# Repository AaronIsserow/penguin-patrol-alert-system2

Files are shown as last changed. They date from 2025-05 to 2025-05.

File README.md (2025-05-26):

# 🐧 Penguin Patrol Alert System

## Table of Contents

- [Project Overview](#project-overview)  
- [Key Features](#key-features)  
- [Architecture & Tech Stack](#architecture--tech-stack)  
- [Mechanical Design & 3D Printing](#mechanical-design--3d-printing)
- [Motion Detection](#motion-detection)
- [Installation & Setup](#installation--setup)

---

## Project Overview

**Penguin Patrol Alert System** is a full-stack web application developed for **EEE4113F** at the University of Cape Town. It integrates real-time predator detection (via computer vision and a Raspberry Pi NoIR camera) with a two-axis pan–tilt gimbal and non-lethal deterrent actuation. Alerts are stored and displayed through a user-friendly dashboard, ensuring rapid intervention to protect the De Hoop penguin colony.

---

## Key Features

- 🎥 **Live Video Streaming** with motion-detection overlays  
- 🔴 **Real-Time Alerts** stored in Supabase and pushed via WebSockets  
- 🛰️ **Pan–Tilt Gimbal Control** for ±90° tracking accuracy  
- 💧 **Non-Lethal Deterrent** (configurable water-jet or laser)  
- 📊 **Dashboard & Analytics** with CSV export  
- 🔧 **Modular Mechanical Design** with 3D-printed submodules

### Basic Example Operation

systemuse (2)

---

## Architecture & Tech Stack

| Layer | Technology |
|---|---|
| **Frontend** | React, Tailwind CSS |
| **Backend / API** | Node.js, Supabase (PostgreSQL) |
| **Realtime Comm.**  | Supabase Realtime |
| **Vision & Control**| Python, OpenCV, pigpio, Raspberry Pi OS |
| **3D Modeling** | Fusion 360 (CAD) |
| **3D Printing** | Cura / PrusaSlicer |

---

## Mechanical Design & 3D Printing

Detailed mechanical design ensures precise servo alignment, environmental sealing, and easy assembly. All parts were 3D-printed and validated with FEA before prototyping.

Linking v2

## Assembly

Linking v1

### Printed Components

| Part | Description | Qty |
|---|---|:---:|
| **Pan Module** | Base plate with servo pocket & mounts  |  1  |
| **Tilt Module** | Horizontal servo carrier & gussets |  1  |
| **Enclosure Base**| IP66-ready housing (bottom half) |  1  |
| **Enclosure Lid** | Snap-fit top cover with gasket groove  |  1  |
| **Fence Clip** | Modular mount for fence attachment |  1  |

<p align="center">
  3D Printed Parts
</p>

### Materials & Settings

- **Filament:**  
  - **UV-stable ASA** for outdoor parts  
  - **PLA+** for enclosure prototypes  
- **Printer:** Creality CR-10 / Prusa i3 MK3S+  
- **Layer Height:** 0.2 mm, **Infill:** 20 %, **Walls:** 3 perimeters  
- **Nozzle Temp:** 240 °C (ASA) / 210 °C (PLA+),  
  **Bed Temp:** 100 °C (ASA) / 60 °C (PLA+)

### CAD & STL Files

All source and exported STLs live in the `MechanicalDesign/` folder:
design/
├─ pan_module.f3d pan_module.stl
├─ tilt_module.f3d tilt_module.stl
├─ enclosure_base.f3d enclosure_base.stl
└─ enclosure_lid.f3d enclosure_lid.stl

## Motion Detection

The Penguin Patrol Alert System employs an advanced real-time motion detection algorithm running on a Raspberry Pi with a NoIR camera module. This enables reliable predator detection even under challenging lighting conditions.

- **Algorithm Overview:**  
  - The system captures continuous frames from the NoIR camera and applies frame differencing to highlight regions of change between consecutive images.  
  - To reduce noise and false positives caused by environmental factors (e.g., shadows, lighting changes), a Gaussian blur filter is applied before differencing.  
  - The resulting difference image is thresholded to create a binary mask representing motion regions.  
  - Contours are extracted from this binary mask and filtered based on area and shape criteria to isolate valid moving objects.  
  - Temporal filtering tracks object persistence over multiple frames to avoid transient false detections.  
- **Hardware:** Raspberry Pi Camera Module V2 NoIR is used for its enhanced infrared sensitivity, combined with optional IR LED illumination for night-time detection.  
- **Control Integration:** Upon detection, the Python-based control script commands the pan–tilt gimbal servos via GPIO using pigpio, allowing smooth tracking of detected objects within ±90° range.  
- **Alerting:** Simultaneously, detection events are logged and pushed in real-time to the Supabase backend, enabling live notifications and historical analytics through the web dashboard.  
- **Configuration:** Parameters such as blur kernel size, threshold values, minimum contour area, and tracking persistence are adjustable in the `motionsense.py` file to optimize system performance under varying environmental conditions.

This comprehensive detection pipeline balances sensitivity with robustness, ensuring reliable predator tracking while minimizing false alarms to protect the penguin colony effectively.

## Installation & Setup

1. **Clone the repository**  
   ```bash
   git clone https://github.com/AaronIsserow/penguin-patrol-alert-system2.git

2. **Install Dependencies**
  npm install                  # Frontend & API
3. Create a .env file in the root directory with your API keys:
  - OpenAI API key for chatbot
  - Supabase credentials
4. Start the development server:
    npm run dev

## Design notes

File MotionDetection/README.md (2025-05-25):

# 🛰️ Motion Detection Subsystem — Turret Project

This folder contains the motion detection and control logic used in the automated turret project. It combines lightweight computer vision, real-time hardware actuation, and cloud-based logging to detect and track movement within a camera's field of view.

---

## 📚 Background

### 📷 Motion Detection Overview (Using OpenCV)

The system uses **frame differencing**, a classic motion detection technique, where each incoming frame is compared against a stabilized background. The open source image processing library OpenCV handles the following steps:

- **Frame capture** from the Pi Camera.
- **Grayscale conversion** and **Gaussian blur** to reduce noise.
- **Absolute difference** between the current frame and a reference background.
- **Thresholding** and **morphological operations** to isolate moving regions.
- **Contour detection** to identify the largest significant object.

If the detected contour exceeds a pixel area threshold, it's considered significant motion. The center of the bounding box is calculated and used to point the turret in that direction.

> This method is fast and lightweight, ideal for low-power hardware, but is sensitive to lighting changes and assumes a mostly static background.

---

### 🧰 Hardware Architecture

| Component | Role |
|---|---|
| Raspberry Pi 3B+ | Main processing unit, runs detection and Flask server. |
| Pi Camera V2 NoIR | Captures frames for processing, with infrared sensitivity for low-light. |
| Servo Motors (x2) | Controlled via PWM to adjust turret pan and tilt. |
| IR LED Module (opt.)  | Recommended for improving night detection performance. |

---

## 📁 Folder Contents

| File | Description |
|---|---|
| `motionsense5.py` | Captures video, detects motion, controls servos, logs to Supabase, and streams annotated video. |
| `flask_controller.py` | Flask server exposing `/start`, `/stop`, and `/status` endpoints, also updates system status in Supabase. |

---

## ⚙️ motionsense5.py — Motion Detection Engine

- Initializes camera and background model.
- Detects motion using image differencing + contour filtering.
- Translates motion coordinates to servo angles using a calibrated FOV.
- Controls pan and tilt servos via `pigpio`.
- Logs each detection to a Supabase table with timestamp and location.
- Streams live video with bounding box overlays via a `/video_feed` endpoint.

---

## 🌐 flask_controller.py — Remote API Interface

A lightweight Flask server for remote subsystem control:

**Endpoints:**
- `POST /start` — Launches `motionsense5.py`.
- `POST /stop` — Terminates detection and resets servos.
- `GET /status` — Returns whether detection is active.

It also sets the `status` field in Supabase's `perimeters` table to reflect system state (boot, shutdown, and manual control).

---

## 🔐 Environment Variables

Create a `.env` file:

```dotenv
SUPABASE_URL=https://your-project.supabase.co
SUPABASE_KEY=your-supabase-service-role-key

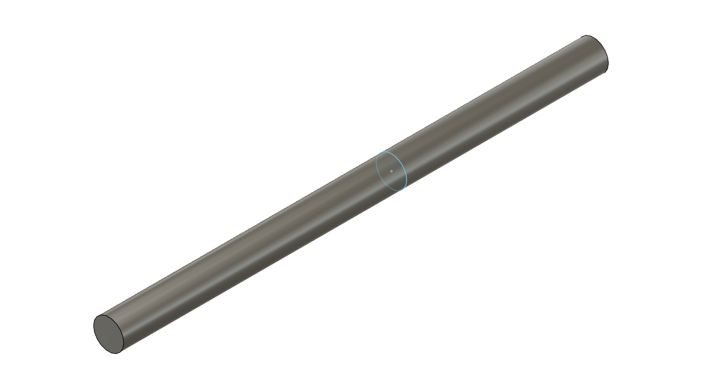
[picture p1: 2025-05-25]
Mechanical Design/HingePin v1.png

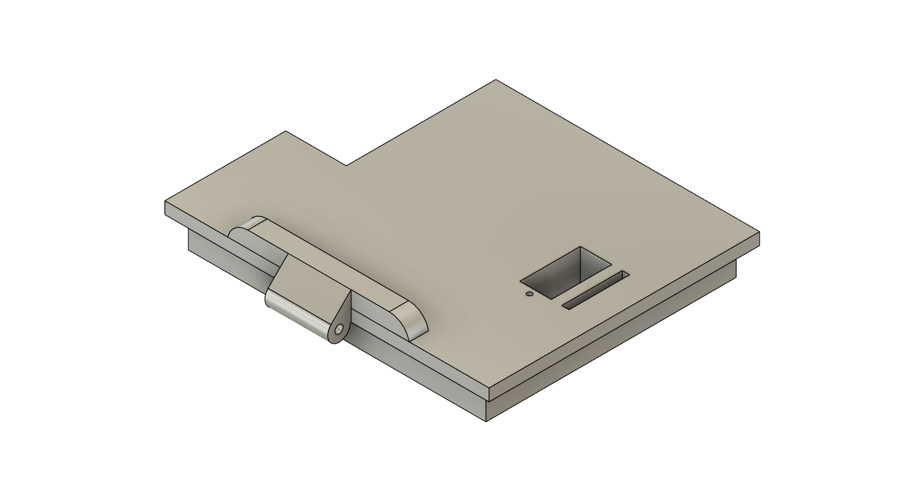
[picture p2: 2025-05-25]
Mechanical Design/CaseLid v10 v7.png

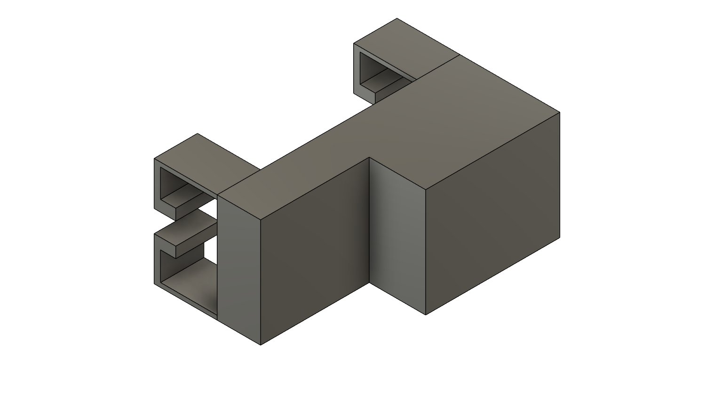
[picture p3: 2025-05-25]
Mechanical Design/FenceConnector v2.png

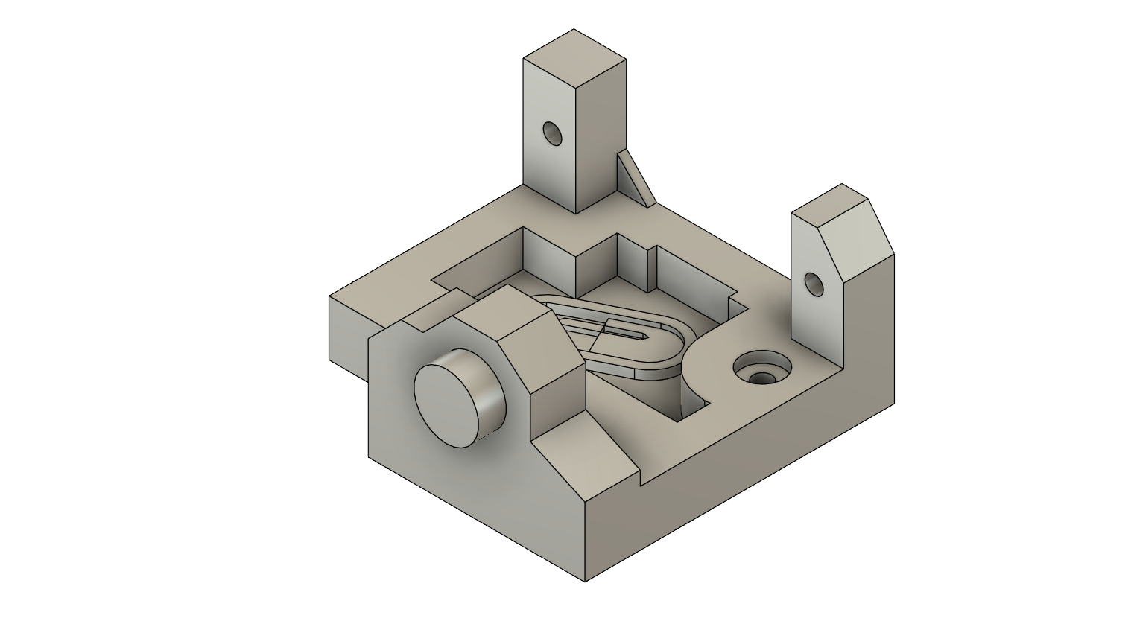
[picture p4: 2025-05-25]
Mechanical Design/Body v11.png

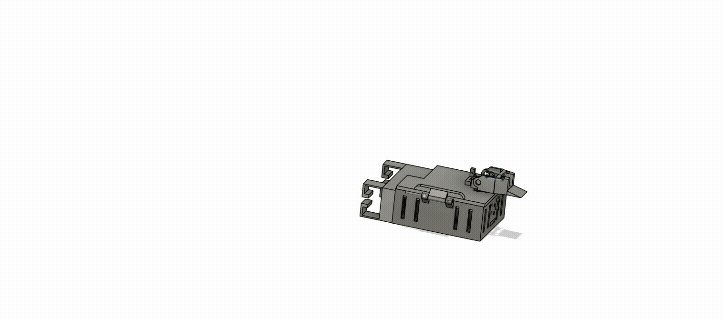
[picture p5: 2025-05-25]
Videos/Linking v1.gif

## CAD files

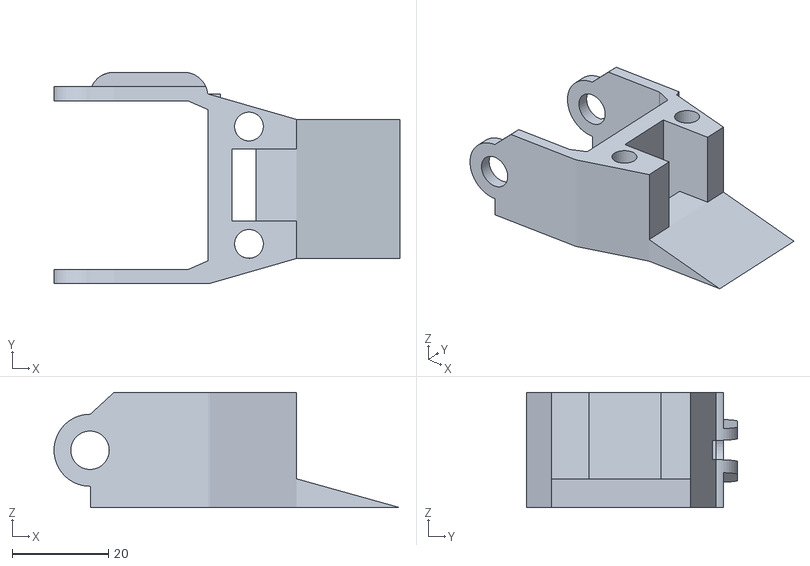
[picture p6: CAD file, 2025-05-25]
Mechanical Design/Tilt.stl
72.0 x 44.0 x 24.0

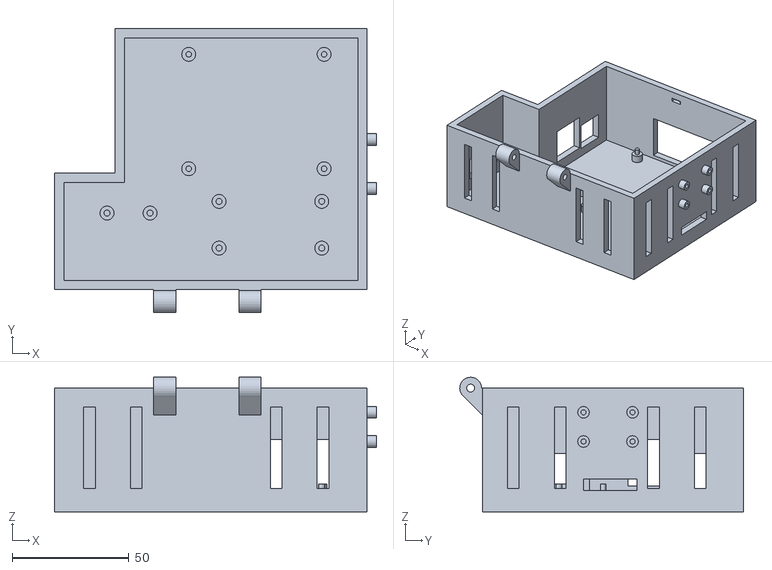
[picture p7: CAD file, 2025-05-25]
Mechanical Design/CaseV30.stl
138.0 x 121.5 x 57.7

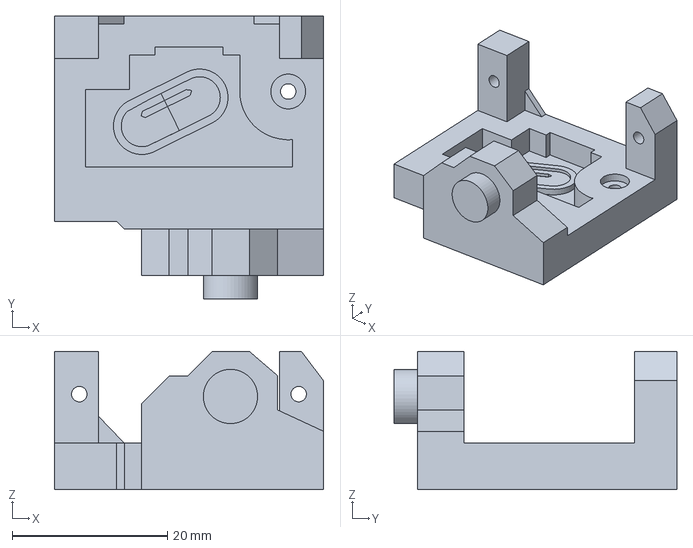
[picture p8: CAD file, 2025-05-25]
Mechanical Design/Final Body.3mf
34.7 x 36.5 x 17.8 mm

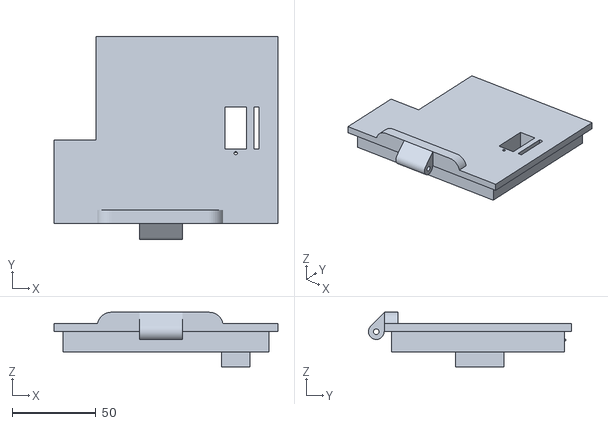
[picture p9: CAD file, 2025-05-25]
Mechanical Design/CaseLidV10V6.stl
134.0 x 121.5 x 32.7

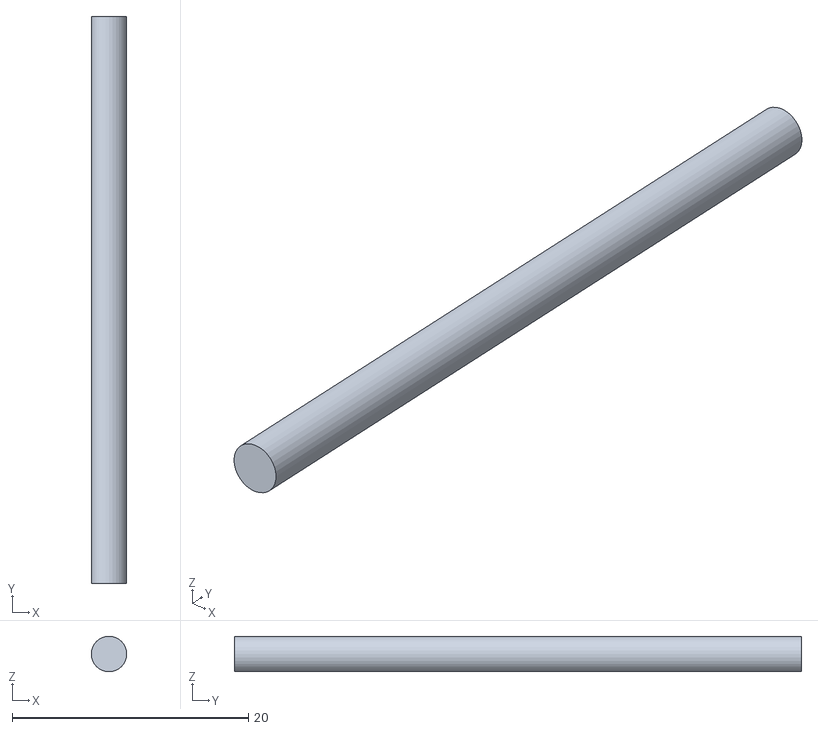
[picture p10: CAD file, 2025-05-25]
Mechanical Design/HingePin.stl
3.00 x 48.0 x 3.00

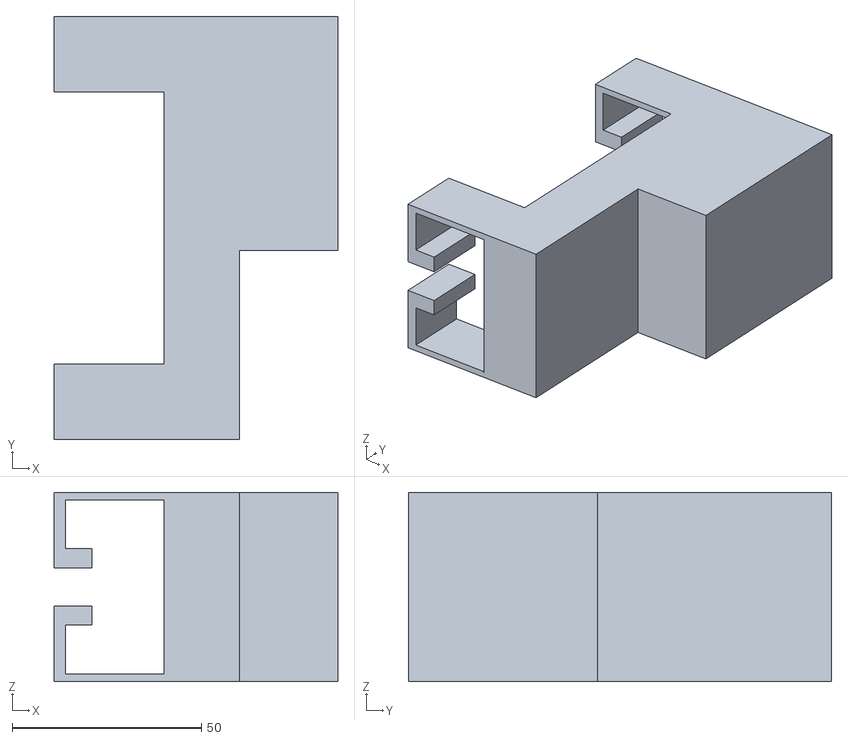
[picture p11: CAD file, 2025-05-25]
Mechanical Design/FenceAttachment.stl
75.0 x 111.8 x 50.0

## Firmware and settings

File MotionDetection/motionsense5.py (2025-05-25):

# --------------------------------------------------------------
# Imports
import cv2
import numpy as np
import time
import RPi.GPIO as GPIO
import pigpio
import math
from datetime import datetime, timedelta
from threading import Thread, Lock
from flask import Flask, Response
from flask_cors import CORS
from picamera2 import Picamera2
from supabase import create_client, Client
from dotenv import load_dotenv
import os

# --------------------------------------------------------------
# Load environment variables from .env file
load_dotenv()

# --------------------------------------------------------------
# Flask App Setup
app = Flask(__name__)
CORS(app)  # Enable Cross-Origin Resource Sharing for frontend integration

# --------------------------------------------------------------
# Supabase Configuration
SUPABASE_URL = os.getenv("SUPABASE_URL")
SUPABASE_KEY = os.getenv("SUPABASE_KEY")
supabase: Client = create_client(SUPABASE_URL, SUPABASE_KEY)

# --------------------------------------------------------------
# Camera Setup
picam2 = Picamera2()
picam2.preview_configuration.main.size = (960, 540)  # Set resolution
picam2.preview_configuration.main.format = "RGB888"
picam2.preview_configuration.align()
picam2.configure("preview")
picam2.start()  # Start video stream

# --------------------------------------------------------------
# Servo Setup
PAN_GPIO = 12
TILT_GPIO = 13
PAN_MIN_ANGLE = -90
PAN_MAX_ANGLE = 90
PAN_OFFSET = 20
TILT_MIN_ANGLE = -30
TILT_MAX_ANGLE = 60
TILT_OFFSET = 20

pi = pigpio.pi()
if not pi.connected:
    raise RuntimeError("Cannot connect to pigpio daemon")

# Convert image center coordinates to servo angles
def pixel_to_angle(cx, cy, frame_w, frame_h):
    dx = cx - frame_w/2
    dy = cy - frame_h/2
    frac_x = dx / (frame_w / 2)
    frac_y = dy / (frame_h / 2)
    pan_angle = -frac_x * (FOV_X_DEG) + PAN_OFFSET
    tilt_angle = frac_y * (FOV_Y_DEG) + TILT_OFFSET
    pan_angle = max(PAN_MIN_ANGLE, min(PAN_MAX_ANGLE, pan_angle))
    tilt_angle = max(TILT_MIN_ANGLE, min(TILT_MAX_ANGLE, tilt_angle))
    return pan_angle, tilt_angle

# Convert angle to PWM pulse width for servo
def angle_to_pw(angle):
    angle = max(-90, min(90, angle))
    pulse = 1500 + (angle / 90.0) * 500
    return max(1000, min(2000, pulse))

# Move servos to target coordinates
def move_servos(cx, cy, frame_w, frame_h):
    pan_angle, tilt_angle = pixel_to_angle(cx, cy, frame_w, frame_h)
    pi.set_servo_pulsewidth(PAN_GPIO, angle_to_pw(pan_angle))
    pi.set_servo_pulsewidth(TILT_GPIO, angle_to_pw(tilt_angle))

# Reset servos and LED when shutting down
def shutdown_servos():
    pi.set_servo_pulsewidth(PAN_GPIO, 0)
    pi.set_servo_pulsewidth(TILT_GPIO, 0)
    pi.write(LED_PIN, 0)
    pi.stop()

# --------------------------------------------------------------
# LED GPIO Setup
LED_PIN = 26
pi.set_mode(LED_PIN, pigpio.OUTPUT)

# --------------------------------------------------------------
# Globals for Motion Detection
first_frame = None
temp_frame = None
stabilized_count = 0
required_stable_frames = 20
MOTION_THRESHOLD = 5000
lock = Lock()
FOV_X_DEG = 62.2 - 15  # Adjusted field of view
FOV_Y_DEG = 48.8
UPDATE_INTERVAL = 0.05
last_update_time = 0
latest_frame = None
frame_lock = Lock()

# --------------------------------------------------------------
# Supabase Logging
def log_motion_event():
    timestamp = datetime.now().isoformat()
    try:
        data = {
            "location": "Perimeter A",
            "time": timestamp,
            "action_taken": "Laser deployed",
            "acknowledged": False
        }
        supabase.table("detections").insert(data).execute()
        print(f"Motion logged to Supabase at {timestamp}")
    except Exception as e:
        print(f"Supabase logging failed: {e}")

# --------------------------------------------------------------
# Identify best contour above a pixel area threshold
def get_best_contour(imgmask, threshold):
    contours, _ = cv2.findContours(imgmask, cv2.RETR_EXTERNAL, cv2.CHAIN_APPROX_SIMPLE)
    best_area = threshold
    best_cnt = None
    for cnt in contours:
        area = cv2.contourArea(cnt)
        if area > best_area:
            best_area = area
            best_cnt = cnt
    return best_cnt

# --------------------------------------------------------------
# Reset background model for stabilization
def reset_stabilization():
    global first_frame, temp_frame, stabilized_count
    first_frame = None
    temp_frame = None
    stabilized_count = 0
    print("Recalibrating background frame...")

# --------------------------------------------------------------
# Main Motion Detection Loop (runs in thread)
def motion_detection_loop():
    global first_frame, temp_frame, stabilized_count, last_update_time, latest_frame
    motion_active = False
    last_alert_time = None
    print("Waiting for camera to stabilize...")

    recalibration_interval = timedelta(minutes=5)
    last_recalibration_time = datetime.utcnow()

    while True:
        now = datetime.utcnow()
        if now - last_recalibration_time >= recalibration_interval:
            reset_stabilization()
            last_recalibration_time = now

        # Capture frame
        frame = picam2.capture_array()
        gray = cv2.cvtColor(frame, cv2.COLOR_RGB2GRAY)
        gray = cv2.GaussianBlur(gray, (21, 21), 0)

        with lock:
            if first_frame is None:
                if temp_frame is None:
                    temp_frame = gray
                    continue
                delta = cv2.absdiff(temp_frame, gray)
                temp_frame = gray
                diff = cv2.threshold(delta, 10, 255, cv2.THRESH_BINARY)[1]
                diff = cv2.dilate(diff, None, iterations=2)
                motion_pixels = cv2.countNonZero(diff)

                if motion_pixels < 300:
                    stabilized_count += 1
                    if stabilized_count >= required_stable_frames:
                        first_frame = gray
                        print("Stabilized. Motion detection activated.")
                        continue
                else:
                    stabilized_count = 0
                continue

            # Compare current frame to background
            delta = cv2.absdiff(first_frame, gray)
            thresh = cv2.threshold(delta, 30, 255, cv2.THRESH_BINARY)[1]
            thresh = cv2.dilate(thresh, None, iterations=2)

            best_contour = get_best_contour(thresh.copy(), threshold=MOTION_THRESHOLD)

            if best_contour is not None:
                (x, y, w, h) = cv2.boundingRect(best_contour)
                frame_h, frame_w = frame.shape[:2]
                cx, cy = x + w // 2, y + h // 2

                move_servos(cx, cy, frame_w, frame_h)
                pi.write(LED_PIN, 1)  # Turn on LED to indicate motion

                # Draw detection box
                cv2.rectangle(frame, (x, y), (x + w, y + h), (0, 255, 0), 2)
                cv2.putText(frame, "Motion Detected", (10, 20),
                            cv2.FONT_HERSHEY_SIMPLEX, 0.6, (0, 0, 255), 2)

                now = datetime.utcnow()
                if not motion_active:
                    motion_active = True
                    last_alert_time = now
                    log_motion_event()
                    print("Motion started, alert sent.")
                elif (now - last_alert_time).total_seconds() >= 60:
                    log_motion_event()
                    last_alert_time = now
                    print("Motion ongoing, secondary alert sent")
            else:
                pi.write(LED_PIN, 0)  # Turn off LED
                if motion_active:
                    print("Motion stopped")
                    motion_active = False
                    last_alert_time = None

        # Encode frame for live video streaming
        ret, jpeg = cv2.imencode('.jpg', frame)
        if ret:
            with frame_lock:
                latest_frame = jpeg.tobytes()

# --------------------------------------------------------------
# Flask Route: /video_feed returns MJPEG stream
@app.route('/video_feed')
def video_feed():
    def frame_generator():
        while True:
            with frame_lock:
                frame = latest_frame
            if frame:
                yield (b'--frame\r\n'
                       b'Content-Type: image/jpeg\r\n\r\n' + frame + b'\r\n')
            time.sleep(0.05)
    return Response(frame_generator(),
                    mimetype='multipart/x-mixed-replace; boundary=frame')

# --------------------------------------------------------------
# Cleanup GPIO on shutdown
import atexit
atexit.register(shutdown_servos)

# --------------------------------------------------------------
# Start Flask App and motion detection loop
if __name__ == '__main__':
    Thread(target=motion_detection_loop, daemon=True).start()
    app.run(host='0.0.0.0', port=5000, threaded=True)


# --------------------------------------------------------------
# Flask Video Feed Route

@app.route('/video_feed')
def video_feed():
    def frame_generator():
        while True:
            with frame_lock:
                frame = latest_frame
            if frame:
                yield (b'--frame\r\n'
                       b'Content-Type: image/jpeg\r\n\r\n' + frame + b'\r\n')
            time.sleep(0.05)
    return Response(frame_generator(),
                    mimetype='multipart/x-mixed-replace; boundary=frame')

# --------------------------------------------------------------
# Cleanup servos and GPIO on exit

import atexit
atexit.register(shutdown_servos)

# --------------------------------------------------------------
# Run Flask App

if __name__ == '__main__':
    Thread(target=motion_detection_loop, daemon=True).start()
    app.run(host='0.0.0.0', port=5000, threaded=True)

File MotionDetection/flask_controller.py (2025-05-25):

#!/usr/bin/env python3

# --------------------------------------------------------------
# Imports
from flask import Flask, jsonify, request
import subprocess
from flask_cors import CORS
from supabase import create_client, Client
import atexit
from dotenv import load_dotenv
import os

# --------------------------------------------------------------
# Load environment variables from .env file
load_dotenv()

# --------------------------------------------------------------
# Supabase Configuration
SUPABASE_URL = os.getenv("SUPABASE_URL")
SUPABASE_KEY = os.getenv("SUPABASE_KEY")
supabase: Client = create_client(SUPABASE_URL, SUPABASE_KEY)

# --------------------------------------------------------------
# Flask App Setup
app = Flask(__name__)
CORS(app)  # Allow cross-origin requests (for frontend communication)
proc = None  # Global variable to hold reference to the subprocess

# --------------------------------------------------------------
# On boot: set system status to active in Supabase
try:
    supabase.table("perimeters").update({"status": True}).eq("zone", "A").execute()
    print("Supabase perimeter A set to active (True) at boot.")
except Exception as e:
    print(f"Failed to update perimeter status on boot: {e}")

# --------------------------------------------------------------
# Flask Route: Start the motion detection script
@app.route('/start', methods=['POST'])
def start_script():
    global proc
    if proc is None or proc.poll() is not None:
        # Start the Python script as a subprocess
        proc = subprocess.Popen([
            '/home/pi/MotionSenseCode/motionsense/bin/python',
            '/home/pi/MotionSenseCode/motionsense5.py'
        ])
        return jsonify({'status': 'started'})
    else:
        return jsonify({'status': 'already running'})

# --------------------------------------------------------------
# Flask Route: Stop the motion detection script
@app.route('/stop', methods=['POST'])
def stop_script():
    global proc
    if proc and proc.poll() is None:
        proc.terminate()  # Terminate the running script
        proc = None
        return jsonify({'status': 'stopped'})
    else:
        return jsonify({'status': 'not running'})

# --------------------------------------------------------------
# Flask Route: Return system status
@app.route('/status', methods=['GET'])
def status():
    global proc
    if proc and proc.poll() is None:
        return jsonify({'running': True})
    else:
        return jsonify({'running': False})

# --------------------------------------------------------------
# Cleanup: On shutdown, update Supabase status to inactive
def cleanup():
    try:
        response = supabase.table("perimeters").update({"status": False}).eq("zone", "A").execute()
        print("Supabase response:", response)
        if hasattr(response, 'error') and response.error:
            print("Supabase error:", response.error)
        else:
            print("Supabase perimeter A set to inactive (False) on shutdown.")
    except Exception as e:
        print(f"Failed to update perimeter status on shutdown: {e}")

# Register the cleanup function to be called on program exit
atexit.register(cleanup)

# --------------------------------------------------------------
# Run Flask server on startup
if __name__ == '__main__':
    app.run(host='0.0.0.0', port=8000)  # Listen on all interfaces, port 8000

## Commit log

2025-05-19 increased csv detections, fixed little error with camera view, added loading bar
2025-05-25 .STL Files
    [CaseLidV10V6.stl, CaseV30.stl, FenceAttachment.stl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]
2025-05-25 Motion Detection Code Added
    code for hosting flask server on raspberry pi and motionsense code to start the motion detection.
